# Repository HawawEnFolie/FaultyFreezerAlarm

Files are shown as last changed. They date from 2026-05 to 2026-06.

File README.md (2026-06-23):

# Faulty Ultralow-temperature Freezer Alarm

## ⟪ DESCRIPTION ⟫

This repository contains the source code and documentation for a critical telemetry embedded system. Developed during the first year of the BTS CIEL ER program to meet the needs of the UPPA (University de Pau et des Pays de l'Adour) microbiology laboratories, this system monitors the temperature of ultra-low temperature freezers in real time. If the temperature crosses a critical threshold, here -65°C, the system triggers an immediate SMS alert via a 4G LTE cellular network to designated rsearchers so as to reduce as much as possible the time where samples are not correctly frozen.

## ⟪ FEATURES ⟫

**▰ High-Precision Acquisition ⪢** Temperature reading every 10 minutes via an industrial PT100 probe and a MAX31865 amplifier (SPI communication).

**▰ Cellular Connectivity ⪢** Automated messages sent over the mobile data network directly to a WhatsApp group using an HTTP API gateway on a SIMCom A7670E module

**▰ Anti-Spam Logic ⪢** The system includes a software lock to send only one SMS when the threshold is crossed, automatically resetting once the temperature stabilizes below a set level, so as not a flood the target phones with multiple SMS.

**▰ Local Monitoring ⪢** Real-time display of readings and network status on the serial monitor with integrated DEBUG mode as well as screen to show live info about the PT100.

**▰ Ambient Temperature Tracking ⪢** Continuous measurement of the ambient room temperature utilizing a TMP102 sensor.

**▰ Local Alerts & Interface ⪢** An integrated buzzer for immediate audible alarms and an SSD1315 OLED display equipped with 4 integrated buttons for local navigation and control.

## ⟪ HARDWARE REQUIREMENTS ⟫

**▰ Microcontroller & Modem ⪢** LilyGo T-A7670E development board (Based on an ESP32-WROVER with an integrated 4G LTE modem).

**▰ RTD Amplifier ⪢** Adafruit MAX31865 module.

**▰ Sensor ⪢** PT100 temperature probe with 4 wires (can be configured for 2 and 3 wires as well).

**▰ Additional Peripherals ⪢** TMP102 ambient temperature sensor, alert buzzer, and an SSD1315 OLED display module with 4 built-in buttons.

**▰ Power & Connectivity ⪢** Active SIM card (with SMS plan) and suitable power supply for the LilyGo board.

## ⟪ SOFTWARE REQUIREMENTS ⟫

**▰ IDE ⪢** Visual Studio Code with the PlatformIO extension.

**▰ Framework ⪢** Arduino (C++).

## [ Dependencies & Libraries ]

**▰** Adafruit MAX31865 library (Handling of the sensor's analog-to-digital conversion).

**▰** TinyGSM (Seamless handling of AT commands and communication with the SIMCom modem).

## ⟪ LICENSE ⟫
The source code of this project is licensed under **GPLv3**.
The hardware design files (Schematics, PCB, 3D models) are licensed under **CERN-OHL-S v2**.
See the LICENSE and cern_ohl_s_v2.txt files for more details.

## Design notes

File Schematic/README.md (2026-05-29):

# Faulty Ultralow-temperature Freezer Alarm - Schematics

## ⟪ DESCRIPTION ⟫
This directory contains the electronic schematics, PCB layouts, and hardware design files for the **FaultyFreezerAlarm** project. The hardware has been developed iteratively to meet the specific telemetry and monitoring requirements of the UPPA microbiology laboratories.

## ⟪ HARDWARE VERSIONS ⟫
**▰ Version 1.4 (Core System) ⪢** This hardware revision focuses strictly on the essential components required for ultra-low temperature monitoring and remote LTE alerting.
* **Core Components:** LilyGo T-A7670E (ESP32-WROVER with integrated 4G LTE modem), Adafruit MAX31865 RTD amplifier, and the PT100 temperature probe interface.

**▰ Version 2.0 (Full System) ⪢** This major revision expands upon V1.4 by introducing local monitoring capabilities, ambient room tracking, and a physical user interface for on-site interaction.
* **Core Components:** All essential components from V1.4.
* **Added Peripherals:** A **TMP102** ambient temperature sensor, a local alert **buzzer**, and an **SSD1315 OLED display** module equipped with 4 built-in navigation buttons.

## ⟪ DESIGN TOOLS ⟫
**▰ Schematic & PCB Routing ⪢** KiCad 9.0.

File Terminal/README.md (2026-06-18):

# FFA Terminal - Asset Environment Monitoring Interface

## ⟪ DESCRIPTION ⟫

This directory contains the Python-based desktop application used as the central control and telemetry hub for the FaultyFreezerAlarm system. Designed to run locally on a computer connected to the LilyGo T-A7670E (ESP32), it provides a complete graphical user interface to monitor the ultra-low temperature freezers of the UPPA microbiology laboratories. It allows for real-time visualization of sensor data, comprehensive hardware diagnostics, and remote configuration of critical system thresholds without needing to recompile the C++ firmware.

## ⟪ FEATURES ⟫

**▰ Smart Serial Connection ⪢** Includes an auto-detect feature to automatically find the ESP32 on active COM ports and an auto-recovery loop to re-establish the link in case of a hardware drop.

**▰ Core Configuration Management ⪢** Read, edit, and push system thresholds (e.g., `PT100_CRITICAL`, `TMP102_CRITICAL`) directly to the ESP32's non-volatile memory.

**▰ Glossary & Dispatch Hub ⪢** A built-in address book to manage the up to 10 phone numbers of the researchers receiving SMS alerts. Allows syncing numbers to the hardware while keeping researcher names in local volatile RAM.

**▰ Live Telemetry & Graphing ⪢** Real-time plotting of the PT100 and TMP102 temperatures against time. Includes the ability to log this data and export it as `.txt` or `.csv` files for scientific tracking.

**▰ Advanced Modem Diagnostics ⪢** Visual status indicators for the SIMCom LTE modem's connection quality, displaying exact values and quality ratings for RSSI, RSRP, RSRQ, and SINR.

**▰ Remote Hardware Testing ⪢** Dedicated diagnostic routines to verify the integrity of the PT100 probe, the ambient sensor, the modem, and the SIM card. Includes a feature to force a test SMS dispatch and perform a soft reboot of the ESP32.

**▰ Integrated Easter Egg ⪢** Contains a fully playable, top-secret Tower Defense mini-game ("Orchidéfense") hidden within the credits tab, featuring lab-themed enemies and hardware-based defensive towers.

## ⟪ SOFTWARE REQUIREMENTS ⟫

**▰ Language ⪢** Python 3.x

**▰ OS Compatibility ⪢** Windows / Linux / macOS (Tkinter must be supported by the host OS).

## [ Dependencies & Libraries ]

**▰** `tkinter` (Standard GUI library for the interface panels and the mini-game canvas).
**▰** `pyserial` (Handling of the serial communication and COM port polling).
**▰** `matplotlib` (Rendering of the real-time temperature graph and data plotting).

## ⟪ LICENSE ⟫

The source code of this interface is licensed under the **GNU General Public License v3.0 (GPLv3)**. 
See the main repository LICENSE file for more details.

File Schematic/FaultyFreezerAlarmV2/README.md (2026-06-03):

# Faulty Ultralow-temperature Freezer Alarm - Schematics V2.5

## ⟪ DESCRIPTION ⟫

This repository contains the hardware design files (schematics and PCB routing) for version 2.5 of the **FaultyFreezerAlarm** project. The hardware has been iteratively developed to meet the specific telemetry and monitoring requirements of the -80°C freezers at the UPPA microbiology laboratories. 

This major revision builds upon the core system (V1.4) by introducing local monitoring capabilities, ambient room temperature tracking, a physical interface for on-site interaction, and a power outage detection circuit.

## ⟪ TECHNICAL SPECIFICATIONS ⟫

▰ **CAD Software** ➢ KiCad 9.0.

▰ **Design Rules** ➢ Default track width: 20th (0.508 mm).

▰ **Layer Count** ➢ 1 layer (Bottom).

▰ **Core Components** ➢ LilyGo T-A7670E (ESP32-WROVER with integrated 4G LTE modem), Adafruit MAX31865 RTD amplifier, and PT100 temperature probe interface.

▰ **Added Peripherals (V2.5)** ➢ TMP102 ambient temperature sensor, local alert buzzer, SSD1315 OLED display module equipped with 4 built-in navigation buttons, and a voltage divider (R1 10kΩ / R2 20kΩ) connected to the USB VBUS pin for power loss detection.

## ⟪ WIRING SCHEMATIC ⟫

WiringSchemeV2 5

## ⟪ PROJECT STRUCTURE ⟫

▰ **`*.kicad_pro`** ➢ Main KiCad project file.

▰ **`*.kicad_sch`** ➢ Electrical schematic file.

▰ **`*.kicad_pcb`** ➢ Printed circuit board routing file.

## ⟪ HOW TO OPEN THE PROJECT ⟫

▰ **Step 1** ➢ Ensure you have **KiCad (version 9.0 or higher)** installed.

▰ **Step 2** ➢ Clone this repository or download the files.

▰ **Step 3** ➢ Launch KiCad and open the `.kicad_pro` file located in the root directory.

## ⟪ AUTHOR ⟫

**Robin Paniagua Desclaux**
*Student in BTS CIEL ER (1st year)*

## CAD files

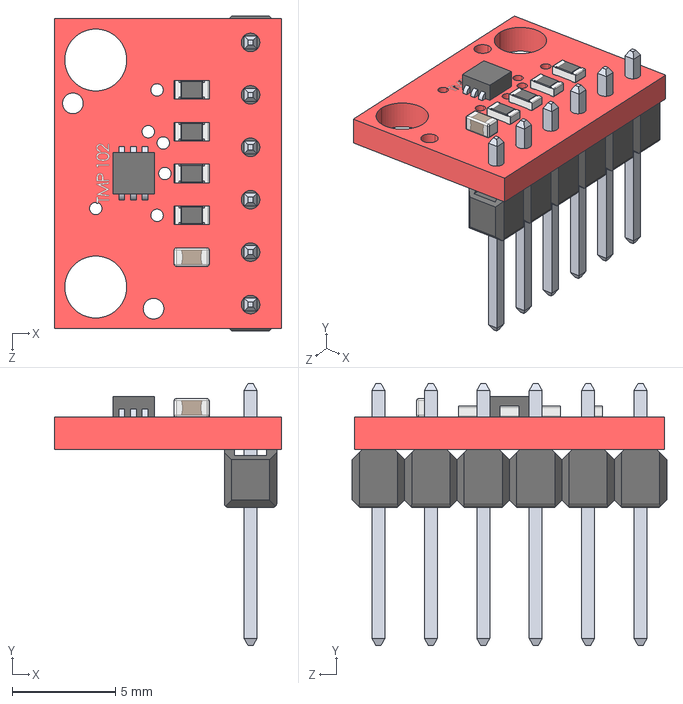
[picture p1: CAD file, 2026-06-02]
Schematic/FaultyFreezerAlarmV2/FootPrint/TMP102.STEP
11.0 x 12.7 x 15.2 mm

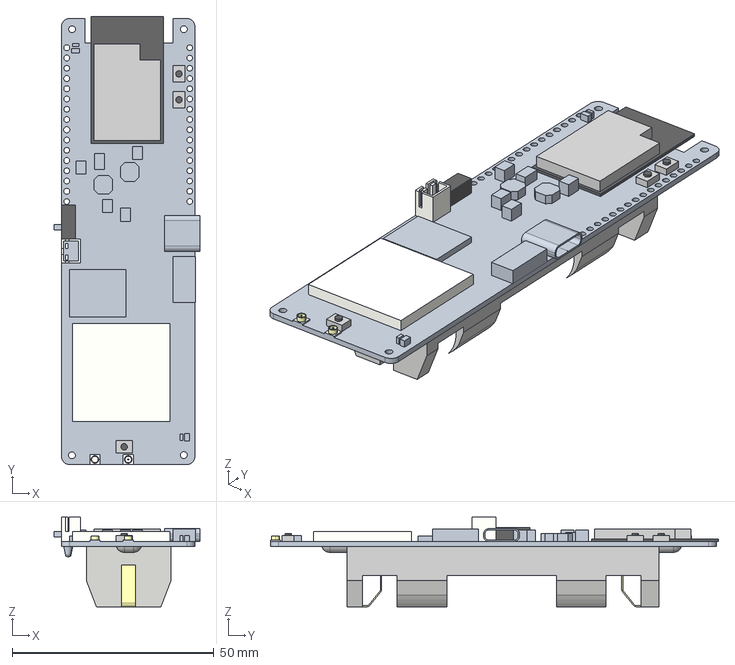
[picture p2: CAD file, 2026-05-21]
Schematic/FaultyFreezerAlarmV2/FootPrint/T-A7670X-Board-3D (1).stp
36.2 x 111.0 x 22.2 mm

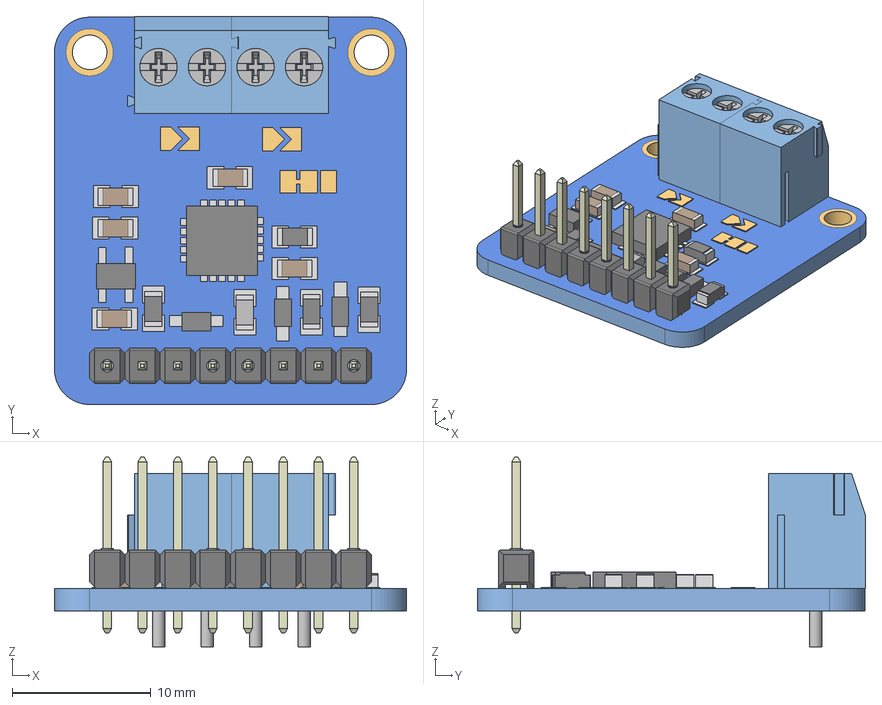
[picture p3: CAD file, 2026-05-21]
Schematic/FaultyFreezerAlarmV2/FootPrint/MAX31865.stp
25.4 x 28.0 x 13.7 mm
plytka
Pin Header 1x4 TH Pitch 2.54mm x 2
TE_1776275-2 x 2

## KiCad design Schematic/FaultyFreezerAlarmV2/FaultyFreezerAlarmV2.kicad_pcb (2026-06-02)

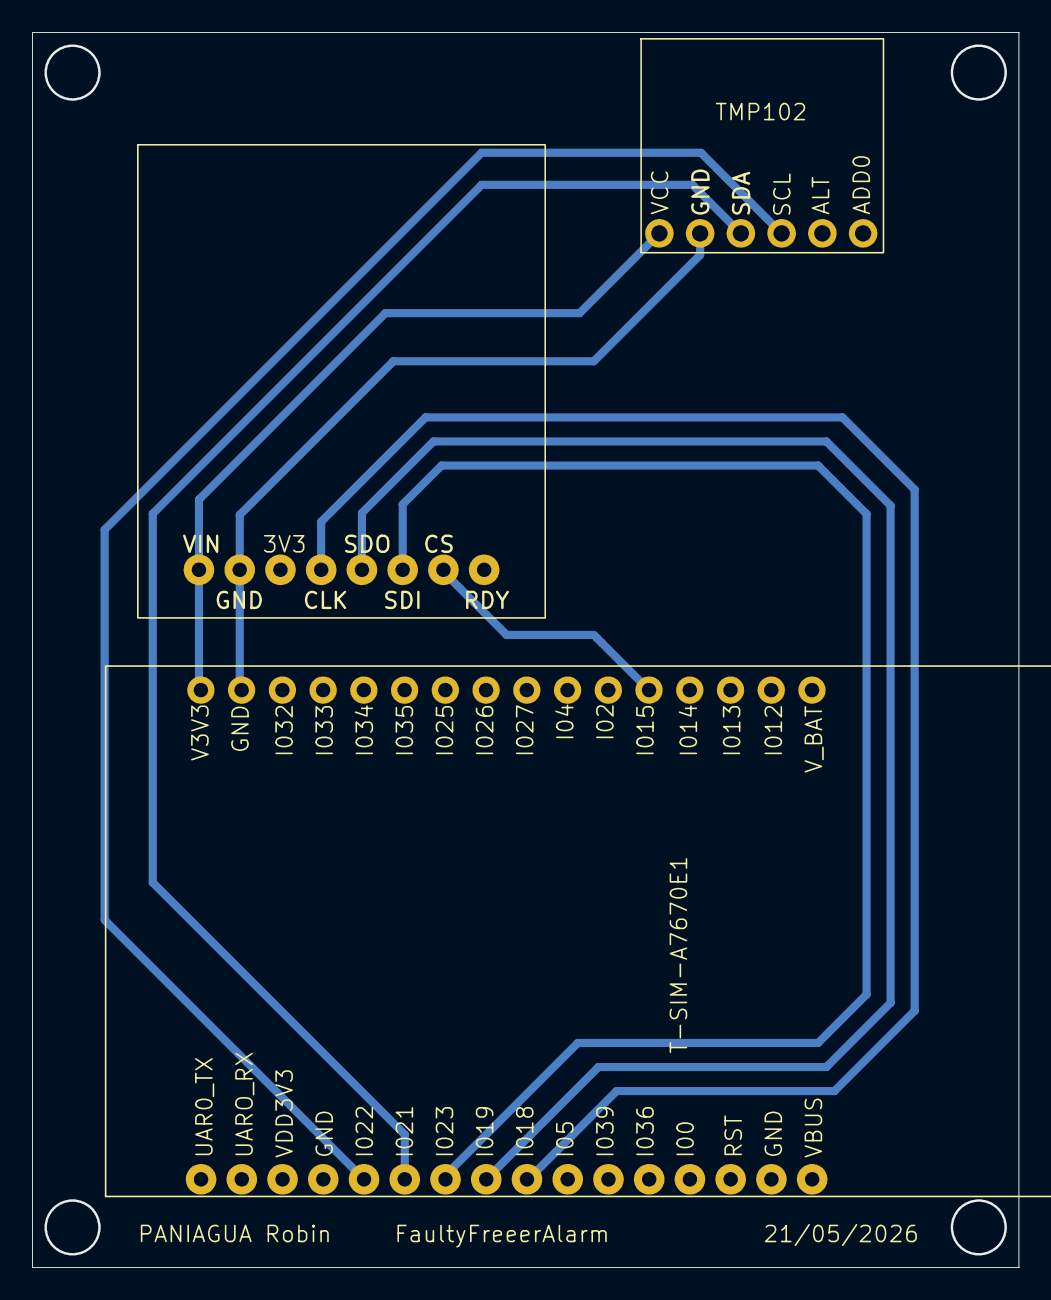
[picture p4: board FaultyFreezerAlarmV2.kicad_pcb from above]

Board: 2 copper layers, 61.5 x 77.0 mm, 3 parts (0 on the bottom side), 8 nets.

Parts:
MAX31865: MAX31865
T-SIM-A7670E1: T-SIM-A7670E
TMP102: TMP102

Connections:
GNDPWR: MAX31865.2 (GND), T-SIM-A7670E1.10 (GND), TMP102.2 (GND), TMP102.6 (ADDO)
unnamed: MAX31865.4 (CLK), T-SIM-A7670E1.18 (I018)
unnamed: MAX31865.7 (CS), T-SIM-A7670E1.15 (I015)
unnamed: MAX31865.6 (SDI), T-SIM-A7670E1.23 (I023)
unnamed: MAX31865.5 (SDO), T-SIM-A7670E1.19 (I019)
unnamed: T-SIM-A7670E1.22 (I022), TMP102.4 (SCL)
unnamed: T-SIM-A7670E1.21 (I021), TMP102.3 (SDA)
VCC: MAX31865.1 (VIN), T-SIM-A7670E1.11 (V3V3), TMP102.1 (VCC)

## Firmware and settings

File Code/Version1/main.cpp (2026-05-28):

#include <Arduino.h>
#include <Wire.h> 
#include <SPI.h>  
#include <Adafruit_MAX31865.h>

// - - - - - [ BUFFER & TINYGSM CONFIGURATION ] - - - - -
#define TINY_GSM_RX_BUFFER 1024 
#define TINY_GSM_MODEM_SIM7600 
#include <TinyGsmClient.h>

// - - - - - [ MODEM CONFIGURATION ] - - - - -
#define MODEM_TX 26
#define MODEM_RX 27
#define MODEM_PWRKEY 4
#define MODEM_RST 5
#define MODEM_DTR 25  
#define BAT_EN 12  
#define GSM_PIN "XXXX"

HardwareSerial SerialAT(1);
TinyGsm Modem(SerialAT);

// - - - - - [ PT100 CONFIGURATION ] - - - - -
#define MAX_CS 15
Adafruit_MAX31865 Thermo = Adafruit_MAX31865(MAX_CS);
#define RREF 430.0 
#define RNOMINAL 100.0 

// - - - - - [ ALERT NUMBERS ] - - - - -
const char* ALERT_NUMBERS[] = {
  "+33000000000",
  "+33111111111",
  "+33222222222",
  "+33333333333",
  "+33444444444"
};
String TARGET_FREEZER = "Micro-biology freezer n°2";
const int NUMBER_COUNT = sizeof(ALERT_NUMBERS) / sizeof(ALERT_NUMBERS[0]);

// - - - - - [ THRESHOLDS ] - - - - -
const float CRITICAL_THRESHOLD = -65.0; 
const float TOO_COLD_THRESHOLD = -100.0; 
const float TOO_HOT_THRESHOLD  = 15.0;   

const unsigned long READ_INTERVAL = 10000;
unsigned long lastReadTime = 0;

// - - - - - [ ANTI-SPAM FLAGS ] - - - - -
bool criticalThresholdAlertActive = false;
bool tooColdAlertActive          = false;
bool tooHotAlertActive           = false;

// - - - - - [ POWER ON ] - - - - -
void PowerOnModem() {
  pinMode(BAT_EN, OUTPUT);
  digitalWrite(BAT_EN, HIGH);
  delay(1000); 

  pinMode(MODEM_DTR, OUTPUT);
  digitalWrite(MODEM_DTR, LOW); 

  pinMode(MODEM_RST, OUTPUT);
  digitalWrite(MODEM_RST, HIGH); 
  delay(200);

  pinMode(MODEM_PWRKEY, OUTPUT);
  digitalWrite(MODEM_PWRKEY, HIGH);
  delay(100);
  digitalWrite(MODEM_PWRKEY, LOW);  
  delay(1500);                     
  digitalWrite(MODEM_PWRKEY, HIGH); 

  delay(6000);
}

// - - - - - [ NUMBER ROUTING LOGIC ] - - - - -
bool SendAlertToAll(String message) {
  int successCount = 0;

  for (int i = 0; i < NUMBER_COUNT; i++) {
    if (!Modem.isNetworkConnected()) {
      Modem.waitForNetwork(10000L); 
    }

    if (Modem.sendSMS(ALERT_NUMBERS[i], message)) {
      successCount++;
    }
    delay(1000);
  }
  return successCount > 0;
}

void setup() {
  Serial.begin(115200);
  delay(1000);
  Serial.println("\n[ INFO ] Starting monitoring program...");

// - - - - - [ PT100 INITIALIZATION ] - - - - -
  Thermo.begin(MAX31865_4WIRE); 
  if (Thermo.readFault()) {
    Serial.println("[ ERROR ] Initial fault detected with PT100 probe.");
    Thermo.clearFault();
  }

// - - - - - [ MODEM SYNCHRONIZATION ] - - - - -
  PowerOnModem();
  SerialAT.begin(115200, SERIAL_8N1, MODEM_RX, MODEM_TX);
  delay(3000);

  if (!Modem.restart()) {
    Serial.println("[ ERROR ] Modem unreachable.");
  } else {
    if (strlen(GSM_PIN) > 0 && Modem.getSimStatus() != 3) {
      Modem.simUnlock(GSM_PIN);
      delay(3000); 
    }

    if (Modem.waitForNetwork(60000L, true)) {
      Serial.println("[ INFO ] Modem connected to the 4G cellular network.");
    } else {
      Serial.println("[ ERROR ] Unable to register on the mobile network.");
    }
  }
  Serial.println("[ INFO ] Real-time monitoring started.");
}

void loop() {
  if (millis() - lastReadTime >= READ_INTERVAL) {
    lastReadTime = millis();

    uint16_t rtd = Thermo.readRTD();
    float Temperature = Thermo.temperature(RNOMINAL, RREF);

    if (Thermo.readFault()) {
      Serial.println("[ ERROR ] Fault or disconnection on PT100 probe! Reading cancelled.");
      Thermo.clearFault();
      return;
    }

    Serial.print("[ INFO ] Temperature: ");
    Serial.print(Temperature);
    Serial.println(" °C");

// - - - - - [ TOO COLD ] - - - - -
    if (Temperature < TOO_COLD_THRESHOLD) {
      if (!tooColdAlertActive) {
        String msg = "ALERT '" + TARGET_FREEZER + "': Abnormally LOW temperature at " + String(Temperature, 2) + " C.";
        if (SendAlertToAll(msg)) tooColdAlertActive = true;
      }
    } else {
      if (tooColdAlertActive) {
        tooColdAlertActive = false; // Rearm
      }
    }

// - - - - - [ TOO HOT ] - - - - -
    if (Temperature > TOO_HOT_THRESHOLD) {
      if (!tooHotAlertActive) {
        String msg = "MAJOR ALERT '" + TARGET_FREEZER + "': Freezer stopped probe taked out! Temperature at " + String(Temperature, 2) + " C!";
        if (SendAlertToAll(msg)) tooHotAlertActive = true;
      }
    } else {
      if (tooHotAlertActive) {
        tooHotAlertActive = false; // Rearm
      }
    }

// - - - - - [ CRITICAL THRESHOLD ] - - - - -
    if (Temperature > CRITICAL_THRESHOLD && Temperature <= TOO_HOT_THRESHOLD) {
      if (!criticalThresholdAlertActive) {
        String msg = "ALERT '" + TARGET_FREEZER + "': Critical temperature detected at " + String(Temperature, 2) + " C!";
        if (SendAlertToAll(msg)) criticalThresholdAlertActive = true; 
      }
    } else {
      if (Temperature <= CRITICAL_THRESHOLD && criticalThresholdAlertActive) {
        criticalThresholdAlertActive = false; // Rearm
      }
    }
  }
}

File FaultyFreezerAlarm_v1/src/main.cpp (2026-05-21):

#include <Arduino.h>
#include <Wire.h> 
#include <SPI.h>  
#include <Adafruit_MAX31865.h>

// - - - - - [ CONFIGURATION BUFFER & TINYGSM ] - - - - -
#define TINY_GSM_RX_BUFFER 1024 
#define TINY_GSM_MODEM_SIM7600 
#include <TinyGsmClient.h>

// - - - - - [ CONFIGURATION MODEM ] - - - - -
#define MODEM_TX     26
#define MODEM_RX     27
#define MODEM_PWRKEY 4
#define MODEM_RST    5
#define MODEM_DTR    25  
#define BAT_EN       12  
#define GSM_PIN      "4545"

HardwareSerial SerialAT(1);
TinyGsm Modem(SerialAT);

// - - - - - [ CONFIGURATION PT100 ] - - - - -
#define MAX_CS       15
Adafruit_MAX31865 Thermo = Adafruit_MAX31865(MAX_CS);
#define RREF         430.0 
#define RNOMINAL     100.0 

// - - - - - [ VARIABLES ] - - - - -
const char* NUMEROS_ALERTE[] = {
  "+33000000000", // Personne n°1 > Xxxxx XXXXXX
  "+33000000000", // Personne n°2 > Xxxxx XXXXXX
  "+33000000000", // Personne n°3 > Xxxxx XXXXXX
  "+33000000000", // Personne n°4 > Xxxxx XXXXXX
  "+33000000000"  // Personne n°5 > Xxxxx XXXXXX
};
String CONGELATEUR_CIBLE = "congelateur ARN dans chambre froide";
const int NOMBRE_NUMEROS = sizeof(NUMEROS_ALERTE) / sizeof(NUMEROS_ALERTE[0]);
const unsigned long INTERVALLE_LECTURE = 10000;
unsigned long DernierReleve = 0;

// - - - - - [ SEUILS DE DÉTECTION ] - - - - -
const float SEUIL_CRITIQUE   = -65.0;
const float SEUIL_TROP_FROID = -100.0;
const float SEUIL_TROP_CHAUD = 65.0;

// - - - - - [ BOOLÉENS ANTI-SPAM ] - - - - -
bool AlerteSeuilCritique = false;
bool AlerteTropFroid     = false;
bool AlerteTropChaud     = false;

// - - - - - [ SÉQUENCE D'ALLUMAGE ] - - - - -
void AllumerModem() {
  pinMode(BAT_EN, OUTPUT);
  digitalWrite(BAT_EN, HIGH);
  delay(1000); 

  pinMode(MODEM_DTR, OUTPUT);
  digitalWrite(MODEM_DTR, LOW); 

  pinMode(MODEM_RST, OUTPUT);
  digitalWrite(MODEM_RST, HIGH); 
  delay(200);

  // Impulsion d'allumage Active LOW (Méthode B validée)
  pinMode(MODEM_PWRKEY, OUTPUT);
  digitalWrite(MODEM_PWRKEY, HIGH);
  delay(100);
  digitalWrite(MODEM_PWRKEY, LOW);  
  delay(1500);                     
  digitalWrite(MODEM_PWRKEY, HIGH); 

  delay(6000); // Temps de démarrage du modem
}

// - - - - - [ LOGIQUE DES NUMÉROS ] - - - - -
bool EnvoyerAlerteATous(String message) {
  int NombreSucces = 0;

  for (int i = 0; i < NOMBRE_NUMEROS; i++) {
    if (!Modem.isNetworkConnected()) {
      Modem.waitForNetwork(10000L); 
    }

    if (Modem.sendSMS(NUMEROS_ALERTE[i], message)) {
      NombreSucces++;
    }
    delay(1000);
  }
  return NombreSucces > 0;
}

void setup() {
  Serial.begin(115200);
  delay(1000);
  Serial.println("\n[ INFO ] Initialisation du programme...");

// - - - - - [ INITIALISATION PT100 ] - - - - -
  Thermo.begin(MAX31865_4WIRE); 
  if (Thermo.readFault()) {
    Serial.println("[ ! ERREUR ! ] Problème initial avec la sonde PT100.");
    Thermo.clearFault();
  }

// - - - - - [ SYNCHRONISATION MODEM SUR RÉSEAU 4G ] - - - - -
  AllumerModem();
  SerialAT.begin(115200, SERIAL_8N1, MODEM_RX, MODEM_TX);
  delay(3000);

  if (!Modem.restart()) {
    Serial.println("[ ERREUR ] Pas de réponse du modem.");
  } else {
    if (strlen(GSM_PIN) > 0 && Modem.getSimStatus() != 3) {
      Modem.simUnlock(GSM_PIN);
      delay(3000); 
    }

    if (Modem.waitForNetwork(60000L, true)) {
      Serial.println("[ INFO ] Modem connecté au réseau cellulaire 4G.");
    } else {
      Serial.println("[ ! ERREUR ! ] Impossible de joindre le réseau mobile 4G.");
    }
  }
  Serial.println("[ INFO ] Début de la surveillance.");
}

void loop() {
  if (millis() - DernierReleve >= INTERVALLE_LECTURE) {
    DernierReleve = millis();

    // Lecture et sécurité de la sonde
    uint16_t rtd = Thermo.readRTD();
    float Temperature = Thermo.temperature(RNOMINAL, RREF);

    if (Thermo.readFault()) {
      Serial.println("[ ! ERREUR ! ] Défaut ou coupure de la sonde PT100 ! Lecture annulée.");
      Thermo.clearFault();
      return;
    }

    // Affichage dans le moniteur de l'ordinateur
    Serial.print("[ INFO ] Température relevée : ");
    Serial.print(Temperature);
    Serial.println(" °C.");

// - - - - - [ ALERTE | FROID EXTRÊME ] - - - - -
    if (Temperature < SEUIL_TROP_FROID) {
      if (!AlerteTropFroid) {
        String msg = "[!] ALERTE POUR '" + CONGELATEUR_CIBLE + "' : Température anormalement basse à " + String(Temperature, 2) + " C.";
        if (EnvoyerAlerteATous(msg)) AlerteTropFroid = true;
      }
// - - - - - [ RÉARMEMENT POUR FROID EXTRÊME ] - - - - -
    } else {
      if (AlerteTropFroid) {
        AlerteTropFroid = false; // Réarmement
      }
    }

// - - - - - [ ALERTE | CHAUD EXTRÊME ] - - - - -
    if (Temperature > SEUIL_TROP_CHAUD) {
      if (!AlerteTropChaud) {
        String msg = "[!] ALERTE POUR '" + CONGELATEUR_CIBLE + "' : Température anormalement chaude à " + String(Temperature, 2) + " C.";
        if (EnvoyerAlerteATous(msg)) AlerteTropChaud = true;
      }
// - - - - - [ RÉARMEMENT POUR CHAUD EXTRÊME ] - - - - -
    } else {
      if (AlerteTropChaud) {
        AlerteTropChaud = false; // Réarmement
      }
    }

// - - - - - [ ALERTE | DÉPASSEMENT TEMPÉRATURE CRITIQUE ] - - - - -
    if (Temperature > SEUIL_CRITIQUE && Temperature <= SEUIL_TROP_CHAUD) {
      if (!AlerteSeuilCritique) {
        String msg = "[!] ALERTE POUR '" + CONGELATEUR_CIBLE + "' : Dépassement du seuil des -65°C ! température actuelle : " + String(Temperature, 2) + " C.";
        if (EnvoyerAlerteATous(msg)) AlerteSeuilCritique = true; 
      }
// - - - - - [ RÉARMEMENT POUR DÉPASSEMENT TEMPÉRATURE CRITIQUE ] - - - - -
    } else {
      if (Temperature <= SEUIL_CRITIQUE && AlerteSeuilCritique) {
        AlerteSeuilCritique = false;
      }
    }
  }
}

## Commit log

2026-05-19 Remove wiring diagram for ESP32 connections
    Removed wiring diagram section for ESP32 pinout.
2026-06-02 Replace wiring schematic image in README
    Updated wiring schematic image for version 2.0.
